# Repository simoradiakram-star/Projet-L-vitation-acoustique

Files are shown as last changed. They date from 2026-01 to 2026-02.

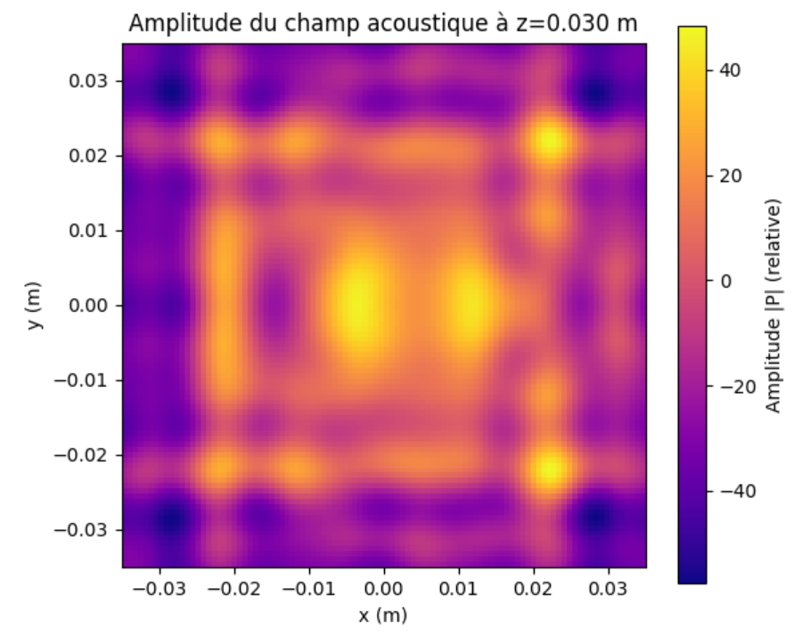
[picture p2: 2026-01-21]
Projet G1-G2/Lévitateur à une plaque/Physique théorique/Photos/vortex 1 plaque.png

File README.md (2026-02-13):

# Système de Lévitation Acoustique

**Projet (G1 / G2) — Centrale Lille**

Développement d'un dispositif expérimental de manipulation sans contact par pinces acoustiques.

Photo_lévitation_1bille_bis

---

### À propos

Ce projet vise à concevoir et réaliser un système de lévitation acoustique à **faible coût**. L'objectif principal est de permettre la manipulation sans contact d'objets millimétriques (tels que des billes de polystyrène ou de petits insectes) dans l'air.

Ce travail s'inscrit dans la continuité des recherches du groupe **AIMAN-FILMS (IEMN)**, qui développe des technologies de pinces acoustiques pour des applications biomédicales (déplacement de cellules en milieu stérile). Notre prototype adapte ces concepts pour une application macroscopique dans l'air.

---

### 1. Objectifs

* **Conception :** Réaliser un prototype fonctionnel intégrant l'électronique et la structure mécanique.
* **Manipulation :** Réussir la lévitation stable d'objets millimétriques.
* **Démonstration :** Prouver la faisabilité d'applications potentielles (ex: manipulation d'échantillons fragiles).

### 2. Technologies et Compétences

Ce projet mobilise des compétences pluridisciplinaires :

* **Hardware / Électronique :** Soudure de cartes électroniques, pilotage de transducteurs.
* **Système embarqué :** Programmation sur Arduino.
* **Mécanique :** Modélisation et Impression 3D de la structure (support des transducteurs).
* **Physique :** Principes des ondes stationnaires et de la pression de radiation acoustique.

### 3. Partenaires et Encadrement

Ce projet est réalisé en partenariat avec le groupe **AIMAN-FILMS** de l'**IEMN** (Institut d'Électronique, de Microélectronique et de Nanotechnologie).

### 4. Contacts académiques

* **Olivier Bou Matar-Lacaze** (Centrale Lille / IEMN)
* **Abdelkrim Talbi** (Centrale Lille / IEMN)

---

Voici l'architecture globale du GitHub :

```
└── Projet-Levitation-acoustique
    ├── Lévitateur à deux plaques
    │   ├── Electronique
    │   │   ├── Circuits
    │   │   └── Composants
    │   ├── Informatique
    │   │   └── Communication 2 Arduino
    │   ├── Notices
    │   ├── Physique Théorique
    │   │   ├── Calcul des phases
    │   │   └── Photos
    │   └── Résultats
    │
    ├── Lévitateur à une plaque
    │   ├── Electronique
    │   │   ├── Circuits
    │   │   └── Composants
    │   ├── Informatique
    │   │   ├── Code Arduino Mega
    │   │   │   ├── DriverMega
    │   │   │   └── NewDriverMega
    │   │   └── Codes Arduino Mega
    │   │       └── DriverMega
    │   ├── Notices
    │   ├── Physique théorique
    │   │   ├── Calcul des phases
    │   │   └── Photos
    │   └── Résultats
    │
    └── TinyLev
        └── Résultats
```

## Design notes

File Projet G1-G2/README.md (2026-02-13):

# 📁 Nos Prototypes

Ce répertoire contient 3 dossiers permettant d'identifier clairement les 3 prototypes réalisés durant notre projet, regroupés ici :

3 protos

## 1. TinyLev (Prototype de Validation)

Le **TinyLev** est un lévitateur à ondes stationnaires.

* **Objectif** : Valider les principes fondamentaux de la lévitation acoustique et tester la chaîne d'amplification.
* **Caractéristique** : Utilise deux supports imprimés en 3D suivant une courbe prédéfinie pour focaliser les ultrasons au centre.

TinyLevenfonctionnement (1)

## 2. Lévitateur à Simple Plaque

Ce prototype marque le passage au contrôle dynamique via une matrice unique de **8x8 transducteurs**.

* **Capacités** : Permet de tester les algorithmes de calcul de phase (**Optimizer** et **Vortex**).
* **Limites** : Bien qu'il valide la création de pièges acoustiques, la force de lévitation reste limitée par l'absence d'une source d'opposition, rendant le piégeage d'objets lourds complexe.



## 3. Lévitateur à Double Plaques

Version la plus aboutie du projet, elle intègre deux matrices de transducteurs placées face à face.

* **Fonctionnement** : Génère des ondes stationnaires contrôlées par la synchronisation des deux plaques.
* **Avantages** :
* Augmentation considérable de la **force de piégeage**.
* **Stabilité supérieure** permettant la manipulation de liquides ou de plusieurs particules simultanément.

Photo_lévitation_1bille_bis

---

*Pour comprendre le déroulement de notre projet plus en détail et avoir une vue d'ensemble, vous pouvez vous référer à la documentation technique située à la racine de ce dossier.*

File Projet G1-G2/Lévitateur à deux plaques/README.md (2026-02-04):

# Prototype 3 : Lévitateur à Double Plaque

Ce prototype représente l'aboutissement du projet de lévitation acoustique. En utilisant deux matrices de 64 transducteurs (8x8) placées en vis-à-vis, il permet la création d'**ondes stationnaires**, offrant une force de piégeage et une stabilité nettement supérieures au système monoplaque.

## Améliorations par rapport au Prototype 2

* **Force de lévitation accrue :** L'interaction entre les deux plaques crée des nœuds de pression beaucoup plus profonds, permettant de soulever des objets plus denses ou des liquides ;
* **Stabilité renforcée :** Le confinement acoustique est total, rendant le piège moins sensible aux courants d'air environnants ;
* **Manipulation Multi-particules :** Capacité de gérer plusieurs points de lévitation simultanément sur l'axe vertical grâce aux ondes stationnaires.

## Organisation des dossiers

### 📁 Electronique
Ce dossier détaille l'adaptation matérielle pour deux plaques :
* **Schémas** 
* **Câblage** 

### 📁 Informatique
Ce dossier contient les outils pour la gestion synchronisée :
* **Codes Arduino** 
* **Génération de phases** 

### 📁 Physique théorique
* **Calcul des phases** 
* **Comparaisons**

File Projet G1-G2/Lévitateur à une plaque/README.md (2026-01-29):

# Prototype 2 : Lévitateur à Simple Plaque (Monoplaque)

Ce prototype constitue la deuxième phase du projet. Il marque le passage d'une géométrie fixe à un système dynamique piloté par logiciel, utilisant une matrice plane de **8x8 transducteurs**.

## Raison d'être

L'objectif de ce prototype était de s'affranchir des contraintes physiques du TinyLev pour explorer la manipulation logicielle. Il a servi de banc d'essai pour :

* L'implémentation de la **modulation de phase** individuelle pour chaque transducteur ;
* La création de pièges acoustiques (points de pression) par calcul algorithmique ;
* La mise en place d'une architecture électronique capable de gérer 64 transducteurs.

## Fonctionnalités

* **Contrôle Dynamique** : Capacité à modifier la position du piège acoustique sans déplacer physiquement les transducteurs ;
* **Algorithmes Avancés** : Test et validation des méthodes **Optimizer** et **Vortex** ;
* **Interface Arduino/Python** : Liaison entre les scripts de calcul de phase (Python) et l'exécution matérielle (Arduino Mega).

## Limites

* **Force de lévitation** : En l'absence d'une plaque opposée pour créer des ondes stationnaires parfaites, la force de piégeage reste relativement faible (pression de radiation seule).
* **Stabilité** : Les objets sont sensibles à toute intervention autour de la plaque, notamment par manque de force de lévitation.

## Évolution : Vers le Prototype 3 (Double Plaque)

Pour pallier le manque de puissance et de stabilité, l'étape suivante consiste à ajouter une seconde plaque identique en vis-à-vis. Cette configuration permettra de créer des **ondes stationnaires** beaucoup plus puissantes, autorisant la lévitation de liquides et une manipulation multi-particules.

---

## 📂 Organisation des dossiers

### 📁 Electronique

Ce dossier contient les documents nécessaires à l'assemblage physique :

* **Schémas** : Diagrammes de câblage de la matrice et des drivers.
* **Montage** : Instructions pour l'interfaçage entre l'Arduino Mega et le shield de puissance.

### 📁 Informatique

Ce dossier regroupe les programmes de pilotage :

* **Génération de phases** : Scripts Python pour transformer des coordonnées (x, y, z) en signaux.
* **Code Arduino** : Firmware optimisé pour l'envoi rapide des données aux transducteurs.

### 📁 Physique théorique

* **Modèles** : Explications sur le potentiel de Gorkov et la pression de radiation.
* **Calcul des phases** : Détails mathématiques sur les fonctions de coût et les méthodes d'optimisation.

---

*Note : Pour une vue d'ensemble du projet, référez-vous à la documentation technique à la racine du dépôt.*

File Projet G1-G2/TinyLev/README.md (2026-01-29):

# Prototype 1 : TinyLev

Le **TinyLev** constitue la première étape concrète du projet. Il s'agit d'un lévitateur acoustique à ondes stationnaires dont la géométrie est fixe, permettant de valider les concepts physiques fondamentaux avant de passer à des systèmes dynamiques.

## 🎯 Raison d'être

L'objectif principal de ce prototype était de :

* Confirmer la faisabilité de la lévitation d'objets millimétriques (billes de polystyrène) ;
* Se familiariser avec la manipulation des transducteurs ultrasonores à 40 kHz.

## ✨ Fonctionnalités

* **Focalisation géométrique** : La courbure de la structure imprimée en 3D assure la convergence des faisceaux ultrasonores vers un point focal central ;
* **Ondes stationnaires** : Création de nœuds de pression stables par interférence d'ondes permettant de piéger des particules à des positions fixes ;
* **Simplicité matérielle** : Pilotage via un Arduino Nano et une alimentation directe, sans besoin de calcul de phase complexe en temps réel.

## ⚠️ Limites

* **Position fixe** : Les pièges acoustiques sont statiques : il est impossible de déplacer la particule une fois lévitée ;
* **Absence de contrôle logiciel** : Le déphasage est induit par la position physique des transducteurs et non par le code.

## ⏭️ Évolution : Vers le Prototype 2 (Monoplaque)

Le succès du TinyLev a démontré que notre électronique de puissance était fiable. Cependant, pour répondre aux objectifs de manipulation dynamique, nous avons dû abandonner la géométrie fixe au profit d'une **matrice plane (8x8)** dont nous contrôlons chacun des transducteurs individuellement.

Le passage au prototype suivant permet d'introduire le **contrôle logiciel des phases**, offrant la flexibilité nécessaire pour déplacer les pièges acoustiques et manipuler les particules dans l'espace.

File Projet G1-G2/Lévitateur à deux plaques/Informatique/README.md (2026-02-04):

# Pilotage Informatique - Prototype Double Plaque

Ce dossier contient les outils logiciels pour le contrôle du lévitateur à deux plaques (128 transducteurs). L'ajout d'une seconde plaque permet de générer des **ondes stationnaires**, offrant une stabilité et une force de lévitation supérieures au prototype précédent.

## Contenu

* **`Codes arduino mega/`** : Firmware optimisé pour l'Arduino Mega. Il gère l'envoi rapide des signaux aux deux matrices de 64 transducteurs via un mapping de ports spécifique ;
* **`Passage_Phases_python_pin.ipynb`** : Notebook de conversion. Il transforme les phases théoriques (calculées via les méthodes Optimizer ou Vortex) en séquences de bits (octets) prêtes à être injectées dans le code Arduino.

## Utilisation Rapide

1. **Calcul :** Définissez vos phases pour les 128 transducteurs dans le Notebook Python (attention à bien différencier la carte maître et esclave) ;
2. **Conversion :** Générez le "bit buffer" (le mapping prend en compte la disposition physique des deux plaques) ;
3. **Flash :** Copiez les octets générés dans la variable `patterns` du code Arduino ;
4. **Synchro :** Assurez-vous que le **pin 2** est relié au **pin 3** de l'Arduino pour la synchronisation du signal 40 kHz.

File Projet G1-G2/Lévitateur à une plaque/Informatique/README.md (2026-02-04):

# Pilotage Informatique - Lévitateur à une plaque

Ce dossier contient l'ensemble des ressources logicielles nécessaires au fonctionnement du prototype de lévitation acoustique à une plaque. 

## Structure du dossier

* **`Codes arduino mega/`** : Contient les scripts `.ino` pour l'Arduino Mega ainsi que les documentations d'explication de ces codes ;
* **`Passage_Phases_python_pin.ipynb`** : Notebook Python permettant de convertir les phases théoriques calculées en données binaires (octets) compréhensibles par l'Arduino.

---

## 🛠️ Instructions d'utilisation

### 1. Calcul des phases et conversion

Avant de téléverser le code sur l'Arduino, vous devez définir la position du piège acoustique :

1. Utilisez les scripts de calcul (Optimizer ou Vortex dans la partie physique théorique de la palque seule) pour obtenir les **phases réelles** (en radians) pour les 64 transducteurs ;
   
2. Ouvrez le notebook **`Passage_Phases_python_pin.ipynb`** ;
   
3. Renseignez vos phases réelles dans le tableau `Phi_64` ;

4. Exécutez le script pour générer le **bit buffer** (liste d'octets) ;
   
5. Copiez ces octets pour l'étape suivante.

### 2. Configuration de l'Arduino Mega

Le code de pilotage est une version optimisée du `DriverMega` original, nommée `NewDriverMega`.

1. Ouvrez le sketch dans le dossier `Codes arduino mega`.
2. Remplacez les octets de la variable `patterns` (ligne 24 environ) par ceux générés par le notebook.

3. **Note sur les motifs (patterns)** : Le code est configuré pour 2 motifs.
    * Pour un piège statique : copiez deux fois le même set de phases.
    * Pour un déplacement : renseignez deux sets de phases proches l'un de l'autre.

4. Sélectionnez la carte **Arduino Mega** dans l'IDE et téléversez le programme.

---

## ⚠️ Précautions

* **Alimentation** : Ne jamais dépasser **29V** sur la carte d'amplification.

* **Connectique** : Vérifiez la continuité des câbles en nappe, car des fils trop fins peuvent causer des pertes de signal.

* **Synchronisation** : Si le signal n'est pas stable à l'oscilloscope, ajustez ou supprimez le nombre de `nop` dans la fonction `WAIT()`.

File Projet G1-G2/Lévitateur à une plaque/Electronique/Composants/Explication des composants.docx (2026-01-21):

Explication des composants

TC 44 27 :

Le TC4427 est un driver de MOSFET conçu pour piloter des transistors MOSFET à grille à haute capacité. Il est couramment utilisé pour amplifier des signaux de commande provenant de microcontrôleurs ou d'autres circuits logiques afin de piloter des charges plus importantes.

### Fonctionnement du TC4427

- Double driver : Il contient deux drivers indépendants capables de fournir un courant de sortie élevé (jusqu'à 1,5 A en crête).
- Commande de MOSFET : Il convertit un signal logique de faible puissance en un signal de puissance plus élevé, permettant d’activer efficacement des MOSFETs.
- Sortie push-pull : Chaque canal possède une sortie de type push-pull (complètement active en montée et en descente), ce qui réduit le temps de commutation et limite les pertes de puissance.

### Caractéristiques principales

- Tension d’alimentation (Vdd) : 4,5V à 18V
- Courant de sortie : 1,5 A (max)
- Temps de commutation rapide :
  - Temps de montée : ~25 ns
  - Temps de descente : ~25 ns
- Entrée compatible logique TTL et CMOS
- Protection contre les inversions de tension d’alimentation

### Utilisation du TC4427

Le TC4427 est utilisé dans plusieurs applications, notamment :

1. Commande de MOSFETs : Pour piloter des transistors MOSFET dans des circuits de commutation ou d’amplification de puissance.
2. Alimentation à découpage (SMPS) : Pour améliorer les performances de commutation des transistors dans des convertisseurs DC-DC.
3. Commande de moteurs : Dans les circuits de contrôle de moteurs à courant continu (DC).
4. Commande de relais et solénoïdes : Pour activer des charges inductives plus importantes.
5. Circuits RF et haute fréquence : Grâce à ses temps de commutation rapides.

### Exemple de schéma d'utilisation

Si l'on souhaite piloter un MOSFET de puissance (ex : IRF540) avec un signal logique 5V issu d'un microcontrôleur (ex : Arduino), voici un schéma de base :

markdown

CopierModifier

+12V

│

│

┌┴┐

Drain │MOSFET│

└┬┘

│

├───(Charge)

│

│

GND

Le TC4427 est connecté ainsi :

- Vdd = 12V (ou 5V si besoin)
- Entrée IN = Signal du microcontrôleur (0V/5V)
- Sortie OUT = Connectée à la grille du MOSFET
- GND = Masse commune avec le circuit

Ce montage permet au microcontrôleur de commander efficacement un MOSFET de puissance sans souffrir des limitations de courant de ses broches de sortie.

### Avantages du TC4427

✅ Peut fonctionner sous une large plage de tensions (4,5V à 18V)
✅ Capable de fournir un fort courant de sortie (jusqu'à 1,5 A)
✅ Temps de commutation rapide, idéal pour des applications haute fréquence
✅ Conception robuste avec protection contre les inversions de tension

En résumé, le TC4427 est un driver MOSFET polyvalent qui améliore la commutation rapide et efficace des transistors MOSFET dans divers circuits de puissance.

### Utilité des broches :

1. IN A (Broche 1) : Entrée du premier driver (signal logique 0V ou 5V).
2. IN B (Broche 2) : Entrée du second driver (signal logique 0V ou 5V).
3. GND (Broche 3, 4, 5) : Masse du circuit (doit être connectée à la masse du système).
4. OUT B (Broche 6) : Sortie du second driver (connectée à la grille du MOSFET ou autre charge).
5. OUT A (Broche 7) : Sortie du premier driver (connectée à la grille du MOSFET ou autre charge).
6. VDD (Broche 8) : Alimentation du circuit (4.5V à 18V, selon l'application).

pour notre situation avec des transducteurs piézoélectriques :

Entrée (IN A/B) : Signal PWM venant d’un microcontrôleur (ex: Arduino).

Sortie (OUT A/B) : Connectée directement au transducteur piézoélectrique.

VDD : Tension adaptée au transducteur (ex: 12V pour une puissance plus élevée).

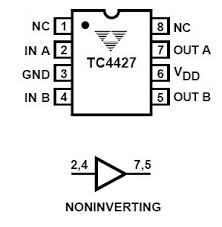
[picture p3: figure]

Les broches NC (Not Connected) sur le TC4427 (broches 1 et 8 dans ton schéma) ne sont pas connectées en interne au circuit du composant.

### Pourquoi y a-t-il des broches NC ?

1. Stabilité mécanique : Elles aident à maintenir la symétrie et la robustesse du boîtier.
2. Compatibilité avec d'autres versions : Certains boîtiers de circuits intégrés ont des broches NC pour faciliter le remplacement par des composants similaires.
3. Future évolution : Ces broches pourraient être utilisées dans des versions futures du circuit intégré.

En résumé, ces broches n'ont pas d'effet sur le fonctionnement du TC4427 et peuvent être laissées non connectées dans un circuit.

Le TC4427 contient deux drivers indépendants, ce qui permet de piloter deux MOSFETs ou charges différentes avec un seul composant. Les sorties sont push-pull, ce qui signifie qu'elles peuvent à la fois fournir du courant (source) et en absorber (sink), facilitant la commutation rapide des transistors.

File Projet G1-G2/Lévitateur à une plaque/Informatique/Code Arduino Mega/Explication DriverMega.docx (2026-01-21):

Documentation technique

Programme DriverMega.ino

Voici le code étudié :

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
#include <avr/sleep.h>

#include <avr/power.h>

#define N_PATTERNS 32

#define N_PORTS 10

#define N_DIVS 10

//ports A C L B K F H D G J

#define COMMAND_SWITCH 0b00000000

#define COMMAND_DURATION 0b00110000

#define MASK_DURATION 0b00111111

#define COMMAND_COMMITDURATIONS 0b00010000

#define WAIT(a) __asm__ __volatile__ ("nop")

#define OUTPUT_WAVE(pointer, d) PORTA = pointer[d*N_PORTS + 0]; PORTC = pointer[d*N_PORTS + 1]; PORTL = pointer[d*N_PORTS + 2]; PORTB = pointer[d*N_PORTS + 3]; PORTK = pointer[d*N_PORTS + 4]; PORTF = pointer[d*N_PORTS + 5]; PORTH = pointer[d*N_PORTS + 6]; PORTD = pointer[d*N_PORTS + 7]; PORTG = pointer[d*N_PORTS + 8]; PORTJ = pointer[d*N_PORTS + 9]

static byte bufferA[N_PATTERNS * N_DIVS * N_PORTS];

static byte bufferB[N_PATTERNS * N_DIVS * N_PORTS];

void setup()

{

//set as output ports A C L B K F H D G J

DDRA = DDRC = DDRL = DDRB = DDRK = DDRF = DDRH = DDRD = DDRG = DDRJ = 0xFF;

//low signal on all of them

PORTA = PORTC = PORTL = PORTB = PORTK = PORTF = PORTH = PORTD = PORTG = PORTJ = 0x00;

//clear the buffers

for (int i = 0; i < (N_PATTERNS * N_DIVS * N_PORTS); ++i) {

bufferA[i] = bufferB[i] = 0;

}

//initial pattern

for (int i = 0; i < (N_PORTS*N_DIVS/2); ++i){

bufferA[i] = 0xFF;

}

//a patterns of 01s at pin 22, for debuging and adjusting times

for(int i = 0; i < N_DIVS; ++i){

if (i % 2 == 0){

bufferA[i * N_PORTS] |= 0b00001000; // HIGH

bufferA[(N_PORTS * N_DIVS / 2) + i * N_PORTS] |= 0b00001000; // HIGH in lower half

} else{

bufferA[i * N_PORTS] &= 0b11110111; // LOW

bufferA[(N_PORTS * N_DIVS / 2) + i * N_PORTS] &= 0b11110111; // LOW in lower half

}

}

// generate a sync signal of 40khz in pin 2

pinMode (2, OUTPUT);

noInterrupts(); // disable all interrupts

TCCR3A = bit (WGM10) | bit (WGM11) | bit (COM1B1); // fast PWM, clear OC1B on compare

TCCR3B = bit (WGM12) | bit (WGM13) | bit (CS10); // fast PWM, no prescaler

OCR3A = (F_CPU / 40000L) - 5; //should only be -1 but fine tunning with the scope determined that -5 gave 40kHz almost exactly

OCR3B = (F_CPU / 40000L) / 2;

interrupts(); // enable all interrupts

//sync in signal at pin 3

pinMode(3, INPUT_PULLUP); //please connect pin3 to pin 2

// disable everything that we do not need

ADCSRA = 0; // ADC

power_adc_disable ();

power_spi_disable();

power_twi_disable();

power_timer0_disable();

power_usart1_disable();

power_usart2_disable();

power_usart3_disable();

//power_usart0_disable();

Serial.begin(115200);

byte bReceived = 0; //octet reçu via Serial

bool byteReady = false; //drapeau : un octet est disponible ?

bool isSwitch = false; //drapeau : commande SWITCH reçue ?

bool isPatternForMe = false; //drapeau : cet octet fait partie du pattern à charger ?

bool isDuration = false; //drapeau : cet octet contient un fragment de durée ?

bool isCommitDurations = false; //drapeau : commande de validation des durées reçue ?

byte nextMsg = 0; //valeur à renvoyer par défaut si commande inconnue

int writtingIndex = 0; //index pour l’écriture progressive d’un pattern

bool emittingA = true; //indique quel buffer (A ou B) est actuellement émis

//Pointeurs vers le début (H) et le milieu (L) du buffer A

byte* emittingPointerH = & bufferA[0];

byte* emittingPointerL = & bufferA[N_PORTS * N_DIVS / 2];

//Sauvegarde des pointeurs “à zéro” pour pouvoir réinitialiser après un switch

byte* emittingPointerZeroH = & bufferA[0];

byte* emittingPointerZeroL = & bufferA[N_PORTS * N_DIVS / 2];

//Pointeurs pour écrire dans le buffer de réception (l’autre buffer)

byte* readingPointerH = & bufferB[0];

byte* readingPointerL = & bufferB[N_PORTS * N_DIVS / 2];

byte durations[N_PATTERNS];

byte durationsBuffer[N_PATTERNS];

// On met tout à zéro

for(int i = 0; i < N_PATTERNS; ++i){

durations[i] = durationsBuffer[i] = 0;

}

// On force la durée du pattern 0 à 1 division temporelle par défaut

durations[0] = durationsBuffer[0] = 1;

byte currentPattern = 0; //motif courant dans la séquence

byte currentPeriods = 0;//compte les divisions émises dans ce motif

byte durationsPointer = 0;//index bit-à-bit lors de la réception des durées

byte currentDuration = 0;//durée lue pour le motif en cours

bool patternComplete = false;//drapeau : motif complètement émis ?

bool lastPattern = false;//drapeau : on est sur le dernier motif (31) ?

byte nextPattern = 0; //motif suivant (courant+1)

byte nextDuration = 0;//durée du motif suivant

bool returnToFirstPattern = false; //drapeau : la séquence doit revenir au motif 0 ?

LOOP:

// Attendre front descendant

while (!(PINE & 0b00100000)); // puis attendre que ça redescende (0)

OUTPUT_WAVE(emittingPointerH, 0); //émission des 8 bits de chaque port à la division 0

byteReady = Serial._dataAvailable(); //on vérifie si un octet est déjà arrivé dans le buffer matériel du Serial

OUTPUT_WAVE(emittingPointerH, 1); //émission de la division 1

bReceived = Serial._peekData(); //on lit l’octet en tête si présent, mais on ne le retire pas du buffer.

OUTPUT_WAVE(emittingPointerH, 2); //émission de la division 2

isSwitch = bReceived == COMMAND_SWITCH; //si l’octet cumulé vaut exactement 0x00, on prépare le flag “switch buffer”.

isCommitDurations = bReceived == COMMAND_COMMITDURATIONS; //même principe pour la validation des durées

OUTPUT_WAVE(emittingPointerH, 3); //émission de la division 3

isPatternForMe = (bReceived & 0b00001111) == 1; //on regarde les 4 LSB pour voir si ce byte contient un fragment du pattern

++currentPeriods; //on incrémente le compteur de périodes déjà émises pour le motif courant.

OUTPUT_WAVE(emittingPointerH, 4); //émission de la division 4

nextMsg = bReceived - 1; //pré-calcule la réponse générique (ack ou message d’erreur minimaliste.

OUTPUT_WAVE(emittingPointerL, 0); //émission de la division 0

isDuration = (bReceived & MASK_DURATION) == COMMAND_DURATION; //on masque les 6 LSB et compare à 0x30 : détecte un byte “durée”.

nextPattern = currentPattern + 1; //on anticipe l’index du motif suivant

OUTPUT_WAVE(emittingPointerL, 1); //émission de la division 1

nextDuration = durations[nextPattern]; //lecture de la durée stockée pour le motif suivant

OUTPUT_WAVE(emittingPointerL, 2); //émission de la division 2

patternComplete = (currentPeriods == durations[currentPattern]);//vrai si on a déjà émis autant de divisions que la durée allouée au motif en cours

OUTPUT_WAVE(emittingPointerL, 3); //émission de la division 3

lastPattern = (currentPattern+1 == N_PATTERNS); //vrai si on était sur le dernier motif (31)

returnToFirstPattern = nextDuration == 0; //vrai si le motif suivant est configuré pour durer 0 divisions.

OUTPUT_WAVE(emittingPointerL, 4); //émission de la division 4

if (patternComplete){

currentPeriods = 0;

++currentPattern;

if (lastPattern || returnToFirstPattern){

currentPattern = 0;

emittingPointerH = emittingPointerZeroH;

emittingPointerL = emittingPointerZeroL;

}else{

emittingPointerH += (N_DIVS * N_PORTS);

emittingPointerL += (N_DIVS * N_PORTS);

}

}

if (byteReady) {

if (isSwitch) {

// --- SWITCH BUFFER ---

Serial.write(COMMAND_SWITCH);

emittingA = !emittingA;

// On swap A↔B pour émission vs. réception

if (emittingA) {

emittingPointerH = &bufferA[0];

emittingPointerL = &bufferA[N_PORTS*N_DIVS/2];

readingPointerH = &bufferB[0];

readingPointerL = &bufferB[N_PORTS*N_DIVS/2];

} else {

emittingPointerH = &bufferB[0];

emittingPointerL = &bufferB[N_PORTS*N_DIVS/2];

readingPointerH = &bufferA[0];

readingPointerL = &bufferA[N_PORTS*N_DIVS/2];

}

emittingPointerZeroH = emittingPointerH;

emittingPointerZeroL = emittingPointerL;

writtingIndex = 0;

durationsPointer = 0;

} else if (isPatternForMe) {

// --- RÉCEPTION D’UN OCTET DE PATTERN ---

// On compose 4 bits hauts et 4 bits bas dans readingPointerH[]

if (writtingIndex % 2 == 0)

readingPointerH[writtingIndex/2] = bReceived & 0xF0;

} else {

readingPointerH[writtingIndex/2] |= (bReceived >> 4);

}

++writtingIndex;

} else if (isDuration) {

// --- RÉCEPTION D’UN OCTET DE DURÉE —

Serial.write( bReceived );

if (durationsPointer % 4 == 0) {

durationsBuffer[durationsPointer / 4] = bReceived & 0b11000000;

} else {

durationsBuffer[durationsPointer / 4] |= (bReceived & 0b11000000) >> (durationsPointer % 4 * 2);

}

++durationsPointer;

} else if (isCommitDurations) {

// --- COMMIT DES DURÉES —

Serial.write(bReceived);

for (int i = 0; i < N_PATTERNS; ++i){

durations[i] = durationsBuffer[i];

}

durationsPointer = 0;

} else {

// --- COMMANDE INCONNUE —

Serial.write(nextMsg);

}

// On consomme enfin l’octet

Serial._discardByte();

}

void loop() {}

## 1. Commentaires d’en-tête et instructions de compilation

Les premiers commentaires (lignes 1–11) indiquent :

- Qu’il faut ajouter trois fonctions inline dans HardwareSerial.h pour accéder aux octets reçus (_dataAvailable(), _peekData(), _discardByte()).
- Que, pour la version Arduino IDE > 1.6, il faut compiler avec l’option -O3 (optimisation vitesse).
- De commenter la ligne power_usart3_disable(); si elle génère une erreur.

Ces ajustements sont purement pour contourner des limitations de la bibliothèque HardwareSerial et d’optimiser le code.

## 2. Inclusion de bibliothèques et définitions de constantes

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
#include <avr/sleep.h>

#include <avr/power.h>

#define N_PATTERNS 32

#define N_PORTS 10

#define N_DIVS 10

//ports A C L B K F H D G J

#define COMMAND_SWITCH 0b00000000

#define COMMAND_DURATION 0b00110000

#define MASK_DURATION 0b00111111

#define COMMAND_COMMITDURATIONS 0b00010000

#define WAIT(a) __asm__ __volatile__ ("nop")

#define OUTPUT_WAVE(pointer, d) PORTA = pointer[d*N_PORTS + 0]; PORTC = pointer[d*N_PORTS + 1]; PORTL = pointer[d*N_PORTS + 2]; PORTB = pointer[d*N_PORTS + 3]; PORTK = pointer[d*N_PORTS + 4]; PORTF = pointer[d*N_PORTS + 5]; PORTH = pointer[d*N_PORTS + 6]; PORTD = pointer[d*N_PORTS + 7]; PORTG = pointer[d*N_PORTS + 8]; PORTJ = pointer[d*N_PORTS + 9]

- COMMAND_SWITCH : Indique “change de buffer” : dès qu’un octet reçu vaut exactement 0, on bascule l’émission de bufferA vers bufferB (ou inverse). Switch permet donc de passer de l’écriture dans un buffer à l’émission de l’autre, garantissant une mise à jour sans artefacts.
- COMMAND_DURATION : Motif de bits en position haute (b5 et b4 à 1) signalant le transfert de données de durée (2 bits × 4). Duration découpe donc chaque durée sur 2 bits, stockés à raison de 4 octets par pattern (2 bits × 4 = 8 bits), grâce au masque.
- MASK_DURATION : Masque pour extraire les 6 bits de poids faible du byte reçu : on l’applique par bReceived & MASK_DURATION pour isoler la partie “commande + payload” sans les bits supérieurs réservés.
- COMMAND_COMMITDURATIONS : Valeur précise (b4 à 1, b5 à 0) qui, une fois reconnue, commande la validation de toutes les durées accumulées dans durationsBuffer[] vers durations[]. CommitDurations confirme donc à l’Arduino qu’il peut désormais utiliser les nouvelles durées pour cadencer la lecture des patterns.

Utilisation dans le programme :

1. Détection d’une commande “switch”

131 | isSwitch = (bReceived == COMMAND_SWITCH);

Si l’octet reçu vaut 0b00000000, on sait que l’hôte veut que l’Arduino bascule le buffer actif d’émission.

2. Détection d’un octet de “durée”

134 | isDuration = ((bReceived & MASK_DURATION) == COMMAND_DURATION);

- On applique bReceived & 0b00111111 pour garder les 6 bits de poids faible.
- Si le résultat vaut 0b00110000, l’octet transporte un fragment de durée à stocker dans durationsBuffer.
3. Détection de la commande de “commit” des durées

131 | isCommitDurations = (bReceived == COMMAND_COMMITDURATIONS);

Quand l’octet reçu vaut 0b00010000, on sait que l’envoi de durées est terminé ; on copie alors durationsBuffer dans durations.

- N_PATTERNS (32) : nombre de motifs/patterns stockés.
- N_PORTS (10) et N_DIVS (10) déterminent la taille des buffers: chaque pattern comporte 10 ports et 10 divisions temporelles.

28 | #define WAIT(a) __asm__ __volatile__ ("nop")

- nop (No OPeration) est une instruction assembleur qui ne fait rien, elle coûte un cycle d’horloge.
- Rôle : insérer un tout petit délai (exactement 1 cycle CPU) à l’endroit où la macro est appelée.
- Paramètre a : n’est pas utilisé dans la macro ; c’est souvent un artifice pour conserver la même syntaxe (WAIT(5) par exemple) si on veut lier la macro à un argument, ou pour documenter l’intention.
- Usage typique : ajuster le placement des instructions en mémoire ou entre deux accès à un port pour garantir un échantillonnage stable ou éviter des métastabilités.

29 29 29 29 29 29 | #define OUTPUT_WAVE(pointer, d) PORTA = pointer[d*N_PORTS + 0]; PORTC = pointer[d*N_PORTS + 1]; PORTL = pointer[d*N_PORTS + 2]; PORTB = pointer[d*N_PORTS + 3]; PORTK = pointer[d*N_PORTS + 4]; PORTF = pointer[d*N_PORTS + 5]; PORTH = pointer[d*N_PORTS + 6]; PORTD = pointer[d*N_PORTS + 7]; PORTG = pointer[d*N_PORTS + 8]; PORTJ = pointer[d*N_PORTS + 9]

Cette macro écrit en un seul appel sur les 10 registres de port (A, C, L, B, K, F, H, D, G, J) la valeur contenue dans un buffer.

- pointer : pointeur sur un tableau byte qui contient, pour chaque “division temporelle” et chaque port, la valeur à appliquer (0 ou 1 dans chaque bit du port).
- d : indice de la “division temporelle” courante (allant de 0 à N_DIVS–1).
- d*N_PORTS + i : calcule l’offset dans le buffer pour le i-ème port (i=0…9).
- Chaque instruction PORTx = …; écrit 8 bits d’un coup sur le port .

## 3. Déclaration des buffers globaux

Deux buffers (A et B) permettent de stocker en double buffer des trames de sortie : pendant qu’on émet l’un, on remplit l’autre via la liaison série.

31 32 | static byte bufferA[N_PATTERNS * N_DIVS * N_PORTS]; static byte bufferB[N_PATTERNS * N_DIVS * N_PORTS];

## 4. Configuration de la fonction setup()

### 4.1. Configuration des broches

On configure d’abord les registres de direction :

34 35 36 37 37 | void setup() { //set as output ports A C L B K F H D G J DDRA = DDRC = DDRL = DDRB = DDRK = DDRF = DDRH = DDRD = DDRG = DDRJ = 0xFF;

- Sur le microcontrôleur ATmega2560 de l’Arduino Mega, chaque port (A, C, L, B, K, F, H, D, G, J) possède un registre DDR (Data Direction Register).
- Mettre un bit à 1 dans DDRX configure la broche correspondante du port en sortie.
- 0xFF en hexadécimal, soit binaire 11111111, fixe tous les 8 bits à 1 : toutes les broches des ports A, C, L, B, K, F, H, D, G et J deviennent des sorties.

On met ensuite à 0 tous les ports :

38 39 39 | //low signal on all of them PORTA = PORTC = PORTL = PORTB = PORTK = PORTF = PORTH = PORTD = PORTG = PORTJ = 0x00;

Le registre PORTX contrôle le niveau logique appliqué aux broches configurées en sortie. En écrivant 0x00 (binaire 00000000), on place tout le port à LOW, c’est-à-dire 0 V sur chaque broche. Ceci garantit qu’au démarrage, aucun signal indésirable n’est émis.

Enfin, on initialise les buffers de motif :

41 42 43 44 | //clear the buffers for (int i = 0; i < (N_PATTERNS * N_DIVS * N_PORTS); ++i) { bufferA[i] = bufferB[i] = 0; }

- Les deux tableaux bufferA et bufferB contiennent les valeurs à envoyer, à chaque pas de temps, sur les 10 ports.
- Leur taille totale est N_PATTERNS * N_DIVS * N_PORTS octets.
  - N_PATTERNS : nombre de motifs différents stockables (32).
  - N_DIVS : nombre de “divisions temporelles” par motif (10).
  - N_PORTS : nombre de ports émis en parallèle (10).
- Cette boucle for met tous les éléments de ces deux buffers à zéro, assurant un état connu (aucun bit à 1) avant de charger un motif ou une séquence.

### 4.2. Initialisation et “pattern” de base

On commence par remplir la moitié haute du bufferA à 0xFF :

46 47 48 49 | //initial pattern for (int i = 0; i < (N_PORTS*N_DIVS/2); ++i){ bufferA[i] = 0xFF; }

- N_PORTS * N_DIVS est le nombre d’octets par pattern.
- Divisé par 2, cela correspond à la première moitié du pattern (on émettra deux “moitiés” successives de N_DIVS divisions).
- En mettant chaque bufferA[i] = 0xFF, on fait en sorte que tous les bits (toutes les broches des 10 ports) soient à 1 (HIGH) pour cette première moitié temporelle.
- La deuxième moitié du buffer (indices ≥ N_PORTS * N_DIVS / 2) reste à 0, donc toutes sorties à LOW.

Cette organisation (division en 2 du buffer) permet de simplifier l’organisation de la mémoire et celle du double buffering ainsi que de gagner en souplesse sur l’émission des patterns.

### 4.3. Debug

On y superpose un signal de 0 et de 1 sur la broche 22 (pour debug):

52 53 54 55 56 56 57 58 59 60 61 62 | //a patterns of 01s at pin 22, for debuging and adjusting times for(int i = 0; i < N_DIVS; ++i){ if (i % 2 == 0){ bufferA[i * N_PORTS] |= 0b00001000; // HIGH bufferA[(N_PORTS * N_DIVS / 2) + i * N_PORTS] |= 0b00001000; // HIGH in lower half } else{ bufferA[i * N_PORTS] &= 0b11110111; // LOW bufferA[(N_PORTS * N_DIVS / 2) + i * N_PORTS] &= 0b11110111; // LOW in lower half } }

- Index de l’octet correspondant à la broche 22 (PA3) pour la division temporelle i :
  - Première moitié → i * N_PORTS + 0 (le port A est à l’emplacement +0)
  - Seconde moitié → (N_PORTS * N_DIVS / 2) + i * N_PORTS + 0
- Masque 0b00001000 : active ou désactive le bit 3 de l’octet, c’est-à-dire PA3.
- Pour i pair on fait un OR (|= 0b00001000) → PA3 = HIGH.
- Pour i impair on fait un AND avec l’inverse (&= 0b11110111) → PA3 = LOW.

Ainsi, au cours des 10 divisions temporelles, PA3 passera alternativement à 1 puis 0 (motif “0101…”), et cela sur les deux moitiés de bufferA.

En gros cela allume la pin22 alternativement (c’est 5 mini créneaux) et cela permet de vérifier que tout fonctionne bien.

### 4.3. Génération d’un signal de synchronisation à 40 kHz (broche 2)

Cette section configure le Timer 3 de l’ATmega pour générer, matériellement, un signal carré synchronisé à 40 kHz sur la broche associée à OC3B (reliée à D2).

66 67 68 69 69 70 70 71 71 72 73 | // generate a sync signal of 40khz in pin 2 pinMode (2, OUTPUT); noInterrupts(); // disable all interrupts TCCR3A = bit (WGM10) | bit (WGM11) | bit (COM1B1); // fast PWM, clear OC1B on compare TCCR3B = bit (WGM12) | bit (WGM13) | bit (CS10); // fast PWM, no prescaler OCR3A = (F_CPU / 40000L) - 5; //should only be -1 but fine tunning with the scope determined that -5 gave 40kHz almost exactly OCR3B = (F_CPU / 40000L) / 2; interrupts(); // enable all interrupts

Elle :

- Met la broche 2 en sortie (c’est là que sortira le signal PWM).

PWM = Pulse Width Modulation → modulation de largeur d’impulsion :

1. C’est un signal numérique (0 ou 1, HIGH ou LOW) dont la fréquence est fixe, mais la durée pendant laquelle il reste à 1 varie.
2. En d’autres termes, on “allume” et “éteint” rapidement une broche pour créer un signal dont la moyenne sur le temps peut représenter une valeur analogique.
- Désactive temporairement toutes les interruptions pour éviter qu’un appel en ISR ne perturbe la configuration fine des registres du timer.
- Mode Fast PWM, TOP = OCR3A
  - Les quatre bits WGM13:WGM10 à 1 sélectionnent le mode 15 (Fast PWM, TOP variable).
  - En mode non-inverting (COM3B1=1), la sortie OC3B passe à HIGH au début de la période (compteur = 0) et se remet à LOW quand le compteur atteint OCR3B.
- CS10 = 1 → on utilise directement la fréquence CPU (F_CPU) sans division.
- CR3A fixe la valeur de comparaison qui détermine la période du PWM :

On soustrait “–5” au lieu de “–1” pour un ajustement au scope, afin d’obtenir précisément 40 kHz à cause de tolérances matérielles.

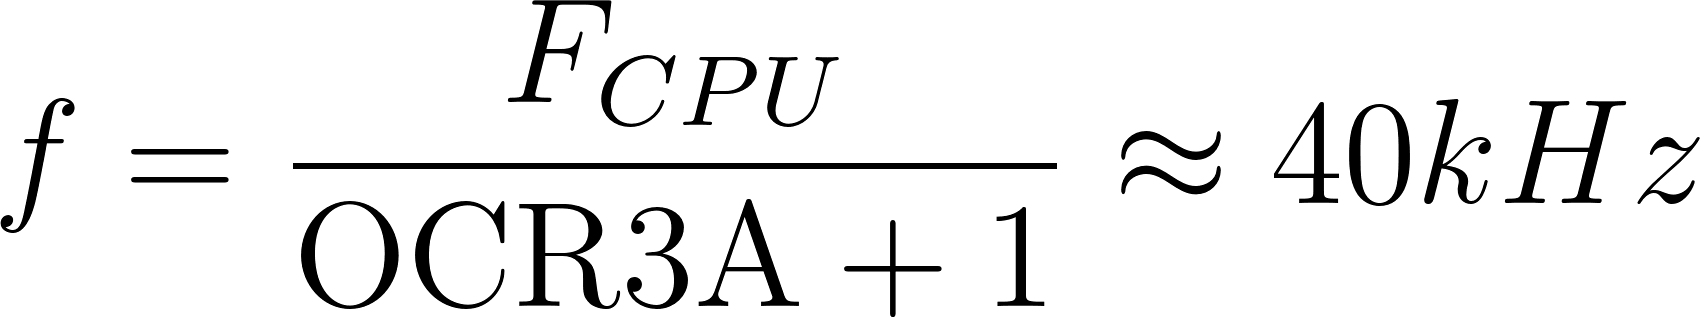
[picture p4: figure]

- OCR3B à la moitié de OCR3A → génère un rapport cyclique 50 %.
- Restaure les interruptions maintenant que le timer est configuré.

A quoi sert une horloge ?

4️⃣ Analogie

Imagine un orchestre :

- Chaque musicien joue sa note quand il voit le chef d’orchestre lever la main.
- Ici :
  - Le signal PWM 40 kHz = chef d’orchestre
  - Les transducteurs = musiciens
  - Chaque impulsion du signal indique quand mettre à jour le pattern sur les sorties.

Sans ce signal, chacun jouerait à sa propre vitesse → le motif acoustique serait détruit.

5️⃣ Résumé

- Le signal de 40 kHz est l’horloge de référence du système.
- Il garantit que tous les transducteurs changent d’état exactement au même moment.
- Sans lui, la lévitation acoustique ne serait pas stable.

### 4.4. Entrée de synchronisation (broche 3)

75 76 | //sync in signal at pin 3 pinMode(3, INPUT_PULLUP); //please connect pin3 to pin 2

On attend un front descendant sur pin 3 connecté à pin 2 pour cadencer la boucle d’émission.

### 4.5. Désactivation des périphériques non utilisés pour économiser l’énergie

79 80 81 82 83 84 85 86 87 88 | // disable everything that we do not need ADCSRA = 0; // ADC power_adc_disable (); power_spi_disable(); power_twi_disable(); power_timer0_disable(); power_usart1_disable(); power_usart2_disable(); power_usart3_disable(); //power_usart0_disable();

On garde tout de même le port USART0 activé afin de pouvoir utiliser la communication série avec l’application Java.

### 3.6. Initialisation du port série et variables de protocole

On initialise tout d’abord le port série en configurant l’USART0 à 115 200 bauds pour l’échange de commandes et de données avec l’hôte (PC ou microcontrôleur maître). :

90 | Serial.begin(115200);

Ensuite, on déclare les variables de réception :

92 93 94 95 95 96 96 97 97 98 98 99 99 | byte bReceived = 0; //octet reçu via Serial bool byteReady = false; //drapeau : un octet est disponible ? bool isSwitch = false; //drapeau : commande SWITCH reçue ? bool isPatternForMe = false; //drapeau : cet octet fait partie du pattern à charger ? bool isDuration = false; //drapeau : cet octet contient un fragment de durée ? bool isCommitDurations = false; //drapeau : commande de validation des durées reçue ? byte nextMsg = 0; //valeur à renvoyer par défaut si commande inconnue int writtingIndex = 0; //index pour l’écriture progressive d’un pattern

Ces drapeaux sont recalculés à chaque itération de la boucle principale pour parser l’octet reçu (bReceived).

Puis, il faut gérer la double bufférisation :

101 101 102 103 104 105 106 107 | bool emittingA = true; //indique quel buffer (A ou B) est actuellement émis //Pointeurs vers le début (H) et le milieu (L) du buffer A byte* emittingPointerH = & bufferA[0]; byte* emittingPointerL = & bufferA[N_PORTS * N_DIVS / 2]; //Sauvegarde des pointeurs “à zéro” pour pouvoir réinitialiser après un switch byte* emittingPointerZeroH = & bufferA[0]; byte* emittingPointerZeroL = & bufferA[N_PORTS * N_DIVS / 2]; //Pointeurs pour écrire dans le buffer de réception (l’autre buffer) byte* readingPointerH = & bufferB[0]; byte* readingPointerL = & bufferB[N_PORTS * N_DIVS / 2];

- emittingPointerH/L pointent sur la moitié active du buffer à émettre (la première moitié des divisions temporelles puis la seconde).
- readingPointerH/L pointent sur la moitié correspondante de l’autre buffer, où les nouveaux motifs seront chargés.
- Quand on reçoit la commande SWITCH, on inverse emittingA et on échange simplement ces pointeurs entre A et B.

Vient alors l’initialisation des durées de pattern :

109 110 111 112 113 114 | byte durations[N_PATTERNS]; byte durationsBuffer[N_PATTERNS]; // On met tout à zéro for(int i = 0; i < N_PATTERNS; ++i){ durations[i] = durationsBuffer[i] = 0; } // On force la durée du pattern 0 à 1 division temporelle par défaut durations[0] = durationsBuffer[0] = 1;

- durations[] stocke pour chaque motif (0 à 31) le nombre de divisions temporelles pendant lesquelles il reste actif.
- durationsBuffer[] sert à accumuler les nouvelles durées reçues avant le commit.
- On met par défaut le pattern 0 à durer 1 division, pour éviter une division par zéro lors du premier cycle.

Finalement, on met à jour les variables qui contrôlent le cycle d’émission :

116 117 118 119 120 121 122 123 124 | byte currentPattern = 0; //motif courant dans la séquence byte currentPeriods = 0;//compte les divisions émises dans ce motif byte durationsPointer = 0;//index bit-à-bit lors de la réception des durées byte currentDuration = 0;//durée lue pour le motif en cours bool patternComplete = false;//drapeau : motif complètement émis ? bool lastPattern = false;//drapeau : on est sur le dernier motif (31) ? byte nextPattern = 0; //motif suivant (courant+1) byte nextDuration = 0;//durée du motif suivant bool returnToFirstPattern = false; //drapeau : la séquence doit revenir au motif 0 ?

- currentPattern et currentPeriods gèrent la progression au sein des divisions temporelles du pattern actif.
- À chaque front de synchronisation, on incrémente currentPeriods ; quand il atteint durations[currentPattern], patternComplete passe à true et on avance currentPattern.
- Si on est arrivé au pattern final (31) ou si la durée du suivant est nulle, on revient au motif 0.

### 3.5. Boucle principale avec goto LOOP

Contrairement au style habituel void loop(), ici on utilise un label LOOP: et un goto pour réduire le code généré par l’IDE.

### 3.5.1. Synchronisation sur front descendant (cycle PWM 40 kHz)

125 126 127 | LOOP: // Attendre front descendant while (!(PINE & 0b00100000)); // puis attendre que ça redescende (0)

Comme cette broche (PE5) est raccordée au signal PWM de pin 2 via pin 3, on se positionne sur le front montant, puis le code suivant attendra la descente effective du signal avant la prochaine itération.

- PE5 correspond à la broche 3 ; ce signal est le reflet du PWM 40 kHz généré sur la broche 2.
- On synchronise ainsi chaque itération de la boucle sur une période complète du signal de référence, garantissant un timing constant.

### 3.5.2. Emission du motif et évaluation du byte série

Chaque itération, on exécute successivement cinq appels à la macro OUTPUT_WAVE(...), envoyant les octets préparés dans emittingPointerH[] pour les divisions temporelles 0→4, puis cinq pour emittingPointerL[], divisions 0→4 de la seconde moitié du pattern :

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
OUTPUT_WAVE(emittingPointerH, 0); //émission des 8 bits de chaque port à la division 0

byteReady = Serial._dataAvailable(); //on vérifie si un octet est déjà arrivé dans le buffer matériel du Serial

OUTPUT_WAVE(emittingPointerH, 1); //émission de la division 1

bReceived = Serial._peekData(); //on lit l’octet en tête si présent, mais on ne le retire pas du buffer.

OUTPUT_WAVE(emittingPointerH, 2); //émission de la division 2

isSwitch = bReceived == COMMAND_SWITCH; //si l’octet cumulé vaut exactement 0x00, on prépare le flag “switch buffer”.

isCommitDurations = bReceived == COMMAND_COMMITDURATIONS; //même principe pour la validation des durées

OUTPUT_WAVE(emittingPointerH, 3); //émission de la division 3

isPatternForMe = (bReceived & 0b00001111) == 1; //on regarde les 4 LSB pour voir si ce byte contient un fragment du pattern

++currentPeriods; //on incrémente le compteur de périodes déjà émises pour le motif courant.

OUTPUT_WAVE(emittingPointerH, 4); //émission de la division 4

nextMsg = bReceived - 1; //pré-calcule la réponse générique (ack ou message d’erreur minimaliste.

OUTPUT_WAVE(emittingPointerL, 0); //émission de la division 0

isDuration = (bReceived & MASK_DURATION) == COMMAND_DURATION; //on masque les 6 LSB et compare à 0x30 : détecte un byte “durée”.

nextPattern = currentPattern + 1; //on anticipe l’index du motif suivant

OUTPUT_WAVE(emittingPointerL, 1); //émission de la division 1

nextDuration = durations[nextPattern]; //lecture de la durée stockée pour le motif suivant

OUTPUT_WAVE(emittingPointerL, 2); //émission de la division 2

patternComplete = (currentPeriods == durations[currentPattern]);//vrai si on a déjà émis autant de divisions que la durée allouée au motif en cours

OUTPUT_WAVE(emittingPointerL, 3); //émission de la division 3

lastPattern = (currentPattern+1 == N_PATTERNS); //vrai si on était sur le dernier motif (31)

returnToFirstPattern = nextDuration == 0; //vrai si le motif suivant est configuré pour durer 0 divisions.

OUTPUT_WAVE(emittingPointerL, 4); //émission de la division 4

Pour chaque division temporelle d :

1. OUTPUT_WAVE écrit en parallèle sur les 10 ports la valeur pointer[d*N_PORTS + i].
2. Au deuxième appel (d=1), on lit si un octet est prêt :
  - byteReady = Serial._dataAvailable();
  - bReceived = Serial._peekData(); On ne consomme pas encore l’octet, juste on le lit pour décider de la suite.
3. Entre les écritures, on calcule divers drapeaux et compteurs en fonction de bReceived :
  - isSwitch, isCommitDurations
  - isPatternForMe (on regarde les 4 LSB (= bit de point faible) pour voir si ce pattern est destiné à cet esclave)
  - nextMsg = bReceived - 1 : valeur par défaut à renvoyer si commande inconnue
  - isDuration pour détecter l’octet de durée
  - nextPattern, nextDuration : préparation pour tester si on doit repasser au motif 0
  - patternComplete dès que le nombre de divisions émises atteint durations[currentPattern]
  - lastPattern si on est sur le dernier motif (31)
  - returnToFirstPattern si la durée du suivant vaut 0

Par cette alternance d’OUTPUT_WAVE et de calculs, on s’assure que l’émission reste cycle-exacte à 40 kHz, tout en “streamant” le protocole série en arrière-plan.

### 3.5.3 Avancement du motif

Après les 10 divisions temporelles, on regarde si patternComplete est vrai :

140 141 142 143 144 145 146 147 148 149 150 151 | if (patternComplete){ currentPeriods = 0; ++currentPattern; if (lastPattern || returnToFirstPattern){ currentPattern = 0; emittingPointerH = emittingPointerZeroH; emittingPointerL = emittingPointerZeroL; }else{ emittingPointerH += (N_DIVS * N_PORTS); emittingPointerL += (N_DIVS * N_PORTS); } }

- currentPeriods remis à zéro pour compter de nouvelles divisions.
- currentPattern incrémenté, ou remis à 0 si fin de séquence ou durée nulle.
- emittingPointerH/L avancent de N_DIVS*N_PORTS octets pour pointer vers la prochaine moitié de buffer à émettre.

### 3.5.4 Gestion du protocole série

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
if (byteReady) {

if (isSwitch) {

// --- SWITCH BUFFER ---

Serial.write(COMMAND_SWITCH);

emittingA = !emittingA;

// On swap A↔B pour émission vs. réception

if (emittingA) {

emittingPointerH = &bufferA[0];

emittingPointerL = &bufferA[N_PORTS*N_DIVS/2];

readingPointerH = &bufferB[0];

readingPointerL = &bufferB[N_PORTS*N_DIVS/2];

} else {

emittingPointerH = &bufferB[0];

emittingPointerL = &bufferB[N_PORTS*N_DIVS/2];

readingPointerH = &bufferA[0];

readingPointerL = &bufferA[N_PORTS*N_DIVS/2];

}

emittingPointerZeroH = emittingPointerH;

emittingPointerZeroL = emittingPointerL;

writtingIndex = 0;

durationsPointer = 0;

} else if (isPatternForMe) {

// --- RÉCEPTION D’UN OCTET DE PATTERN ---

// On compose 4 bits hauts et 4 bits bas dans readingPointerH[]

if (writtingIndex % 2 == 0)

readingPointerH[writtingIndex/2] = bReceived & 0xF0;

} else {

readingPointerH[writtingIndex/2] |= (bReceived >> 4);

}

++writtingIndex;

} else if (isDuration) {

// --- RÉCEPTION D’UN OCTET DE DURÉE —

Serial.write( bReceived );

if (durationsPointer % 4 == 0) {

durationsBuffer[durationsPointer / 4] = bReceived & 0b11000000;

} else {

durationsBuffer[durationsPointer / 4] |= (bReceived & 0b11000000) >> (durationsPointer % 4 * 2);

}

++durationsPointer;

} else if (isCommitDurations) {

// --- COMMIT DES DURÉES —

Serial.write(bReceived);

for (int i = 0; i < N_PATTERNS; ++i){

durations[i] = durationsBuffer[i];

}

durationsPointer = 0;

} else {

// --- COMMANDE INCONNUE —

Serial.write(nextMsg);

}

// On consomme enfin l’octet

Serial._discardByte();

}

- Switch : confirme au maître, échange les rôles des buffers A/B.
- PatternForMe : assemble un motif 10 bits (2×4 bits) dans readingPointerH.
- Duration : stocke progressivement 2 bits×4 octets par motif dans durationsBuffer.
- CommitDurations : valide toutes les nouvelles durées en copiant le tampon tampon.
- Inconnu : renvoie nextMsg = bReceived–1 pour signaler une erreur ou un ack générique.

## 5. Fonction loop() vide

1 2 3 | } void loop() {}

La boucle loop() reste vide puisqu’on utilise goto LOOP dès setup() pour la boucle principale.

Conclusion :

Le programme gère une double-bufferisation de motifs (bufferA, bufferB) envoyés simultanément sur 10 ports à une fréquence de division temporelle fixée (40 kHz). Les motifs et leurs durées sont reçus par le port série selon un protocole léger :

- Switch pour permuter buffer émis/réception,
- PatternForMe pour charger les octets de pattern,
- Duration pour charger les durées de chaque pattern,
- CommitDurations pour valider les durées reçues.

Le tout est synchronisé par un signal PWM 40 kHz (pin 2→pin 3) et optimisé pour la basse consommation en désactivant les périphériques inutiles.

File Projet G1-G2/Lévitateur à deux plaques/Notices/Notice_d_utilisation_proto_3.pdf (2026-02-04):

# NOTICE D’UTILISATION : LÉVITATEUR À DEUX PLAQUES

## Contrôle Synchrone Maître-Esclave (Prototype 3)

### 4 février 2026

## Sommaire

1 Étapes clés | 2
2 Prise en main des codes Arduino | 2
3 Prise en main pratique | 4
A Annexes techniques | 7

## 1 Étapes clés

1. Prise en main des codes Arduino
2. Prise en main pratique

## 2 Prise en main des codes Arduino

Ce troisième prototype nécessitant l’utilisation de 2 plaques de lévitation contrôlables de façon indépendantes, il est alors nécessaire d’utiliser 2 cartes Arduino et donc d’être capable de les faire fonctionner de façon synchrone. Pour ce faire, nous avons mis en place un système maître-esclave. Les codes utilisés sont présentés en Annexe.

Le fonctionnement de ce système est assez basique : les phases à émettre sur chacune des deux plaques sont stockées "en dur" (dans le code) dans chacune des deux cartes Arduino, ce qui permet de ne pas avoir à gérer le transfert des octets de l’Arduino maître vers l’Arduino esclave.

La communication entre les 2 deux cartes Arduino se résume donc à leur synchronisation sur le signal créneau du pin 2 de la carte maître permettant de cadencer l’émission des signaux pour les 64 transducteurs. Le fonctionnement schématisé de la communication entre les 2 programmes est repris par la figure suivante.

Ouverture de la
communication Serial à
115200 bauds

Serial
available
?

Non

Oui

Envoi d’un caractère
quelconque via le Serial
Monitor

Mise sous tension des
2 Arduino

Caractère
reçu par
l’esclave ?

Non

Oui
Envoi de l’octet 0x55 par le maître

Octet reçu
par
l’eclave ?

Non

Tick reçu
sur le pin 3
?

Emission de la partie H du buffer

Emission de la partie L du buffer

LOOP

STOP

Pause de 10 cycles de
processeur

## Initialisation Synchronisation

## Emission

Figure 1 – Schéma explicatif de la communication entre les 2 cartes Arduino

### 2.1 Initialisation

Cette première partie des codes est tout à fait similaire à celle du code NewDriverMega disponible sur GitHub (https://github.com/simoradiakram-star/Projet-Levitation-acoustique) et est commune aux deux cartes Arduino.

Dans cette phase d’initialisation, les deux cartes Arduino configurent les constantes, les différentes variables qui seront utilisées ainsi que l’ensemble des ports parallèles (A, C, L, B, K, F, H, D, G et J) en sortie et les placent à l’état bas afin de garantir un état initial stable pour les transducteurs. Elles effacent ensuite le buffer contenant les données d’émission pour éviter toute valeur résiduelle.

La configuration de l’interruption INT5 (sur la broche 3) est mise en place pour détecter chaque front descendant du signal de synchronisation envoyé par la carte maître ; cette interruption alimente un compteur sync_cnt utilisé comme horloge externe.

Enfin, les modules inutiles du microcontrôleur (ADC, SPI, TWI, certains timers et ports série) sont désactivés afin de réduire la charge et d’assurer un fonctionnement précis et déterministe, ce qui est essentiel pour la génération synchrone des signaux.

Il est à noter que le code maître possède une étape qui est absente dans le code esclave : l’émission du signal de synchronisation à 80 kHz. En effet, la carte esclave n’a pas besoin d’émettre ce signal puisque sa broche 3 est directement connectée à la broche 2 de l’Arduino maître, ce qui lui permet de se synchroniser sur le signal du maître.

Remarque : il est à noter que nous avons fait le choix d’utiliser un signal de synchronisation à 80 kHz et non plus à 40 kHz comme précédemment. Cela résulte uniquement de contraintes informatiques liées au cadencement du processeur de la carte Arduino et permet d’obtenir, en utilisant la méthode ci-après présentée, un signal à 40 kHz pour les 64 transducteurs

### 2.2 Synchronisation

La synchronisation des deux cartes débute par un court protocole d’amorçage sur la liaison série. Avant tout échange automatique, la carte maître attend qu’un caractère (quelconque) soit envoyé depuis le moniteur série de l’utilisateur ; ce premier envoi agit comme un déclencheur manuel permettant de signaler que l’opérateur est prêt et que le système peut s’amorcer.

Lorsque ce caractère reçu, le maître transmet alors l’octet 0x55 à l’esclave. De son côté, l’esclave reste bloqué tant qu’il n’a pas reçu cette valeur, ce qui garantit qu’il ne démarre pas prématurément. Une fois 0x55 reconnu, l’esclave confirme implicitement sa disponibilité en allumant sa LED 13 et les deux cartes basculent dans leur boucle synchronisée.

À partir de ce point, l’horloge commune est fournie par le maître sous forme d’un signal carré de 80 kHz généré par le Timer 3. Chaque front descendant de ce signal, détecté sur INT5, incrémente sur les deux cartes le compteur sync_cnt, qui sert alors de référence temporelle partagée. Grâce à ce double mécanisme — déclenchement manuel, handshake maître-esclave via 0x55, puis synchronisation par horloge matérielle — les deux systèmes démarrent exactement en même temps et exécutent ensuite leurs mises à jour de sorties en parfaite simultanéité.

### 2.3 Emission

Une fois la synchronisation établie, les deux cartes peuvent commencer la phase d’émission. Chacune dispose d’un tableau buffer contenant les états logiques à appliquer successivement aux dix ports parallèles raccordés aux transducteurs. Ces valeurs représentent
les motifs d’excitation ultrasonore en haute résolution temporelle.

Lorsqu’un front descendant du signal de synchronisation est détecté, la fonction wait_ticks() assure que chaque mise à jour survient exactement au bon instant, garantissant un timing strictement identique entre le maître et l’esclave. À chaque tick, les cartes envoient simultanément les tranches successives du motif grâce à la macro OUTPUT_WAVE(), qui écrit en une seule instruction l’ensemble des dix octets sur les ports matériels.

L’organisation en pointeurs emittingPointerH et emittingPointerL permet de structurer les données en deux blocs correspondant aux étapes hautes et basses du motif. Ce mécanisme d’émission, basé sur l’écriture directe dans les registres et synchronisé par une horloge externe, assure une génération parfaitement alignée des ondes ultrasonores, condition indispensable pour obtenir un champ acoustique cohérent et stable.

## 3 Prise en main pratique

L’utilisation des deux Arduino n’étant pas à cette étape du projet optimale, il faut absolument veiller à réaliser les étapes suivantes dans l’ordre et en respectant précisément les recommandations à venir.

### 3.1 Téléversement des codes sur les 2 Arduino

La première étape consiste à téléverser les codes sur les 2 Arduino. Pour ce faire, il faut tout d’abord avoir repéré quel Arduino est connecté à quel port COM de l’ordinateur. Pour obtenir cette information, il suffit de connecter séparément chaque Arduino afin d’identifier à quel port il est associé. Une fois cette information obtenue, vous pouvez téléverser le code Arduino Maître sur l’Arduino contrôlant la plaque du bas et le code Esclave sur l’Arduino contrôlant la plaque du haut.

### 3.2 Connexion des deux Arduino

Il est maintenant temps de connecter l’Arduino maître (contrôlant la plaque du bas) à l’Arduino esclave (contrôlant la plaque du haut). Pour ce faire, il suffit de faire correspondre le connecteur mâle à 6 pins de la carte maître sur le connecteur femelle à 6 pins de la carte esclave en s’assurant que l’on connecte bien le port TX de la carte maître au port RX de la carte esclave (cf. gravures à l’arrière du PCB). Il est également possible d’utiliser un câble en nappe disposant de 6 connecteurs mâle et 6 connecteur femelle, ce qui permet d’augmenter la flexibilité de l’installation en réduisant les contraintes liées à la connexion des deux cartes. Cette solution est présentée en figure suivante.

Remarque : il est impossible de téléverser le code sur l’Arduino esclave lorsque ce dernier a été connecté à l’Arduino maître via son port RX car l’utilisation de ce dernier bloque l’accès à l’ordinateur au port série UART.

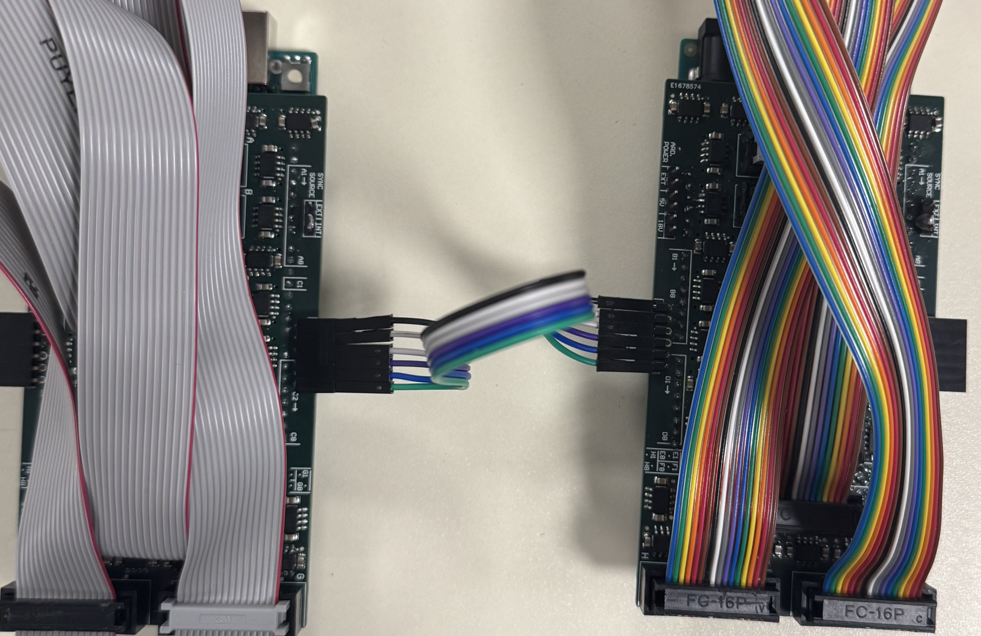
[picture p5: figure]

Figure 2 – Connexion physique des deux cartes Arduino

### 3.3 Lancement de l’émission sur les deux matrices

Une fois les connexions réalisées, il ne reste qu’à lancer l’émission des signaux acoustiques sur les 2 matrices de 64 transducteurs. Pour cela, il suffit d’envoyer via le moniteur série de l’Arduino maître un caractère quelconque (lettre ou chiffre) à l’Arduino esclave. L’envoi de ce caractère permet de synchroniser les 2 Arduino et d’initier l’émission des signaux.

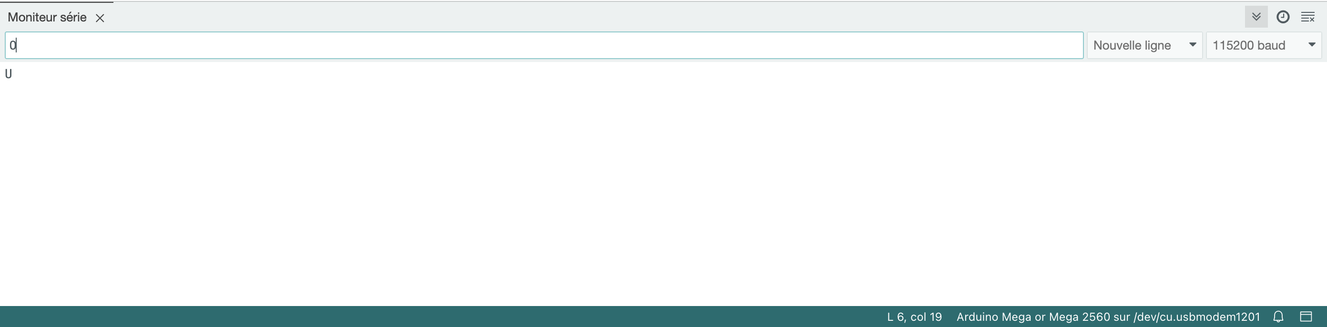
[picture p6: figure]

Figure 3 – Interface du moniteur série pour l’initialisation

### 3.4 Alimentation du dispositif

L’étape finale consiste à alimenter le dispositif avec une tension continue comprise entre 25 et 35 Vpp.

Pour cela, connecter d’abord les fiches banane noire et rouge du câble d’alimentation respectivement sur la borne et la borne + de l’alimentation continue.

Ensuite, connecter la fiche jack du câble d’alimentation à l’un des deux shield d’amplification (maître ou esclave, les deux étant interconnectés). Pour cette étape, se référer au paragraphe "Alimentation du Driver Board" de la notice d’utilisation du prototype à une plaque disponible sur notre GitHub. (https://github.com/simoradiakram-star/Projet-Levitation-acoustique) Enfin, allumer l’alimentation, régler l’intensité environ au tiers du maximum et enfin régler la tension à environ 25 V.

Remarque : par expérience, il est possible qu’un court-circuit apparaisse à la suite d’une mauvaise manipulation du matériel. Ce dernier est souvent repérable à l’aide de l’alimentation continue : si le voyant “CC” de cette dernière est allumé ou l’on entend les calibres de cette dernière passer les uns à la suite des autres, l’éteindre immédiatement afin de préserver le matériel.

Il ne reste plus qu’à faire léviter !

### 3.5 Procédure d’arrêt

Pour éteindre le système, il suffit de commencer par éteindre l’alimentation continue, puis de déconnecter les Arduino de l’ordinateur.

## A Annexes techniques

A.1 | Communication à deux cartes Arduino
A.1.1 | Carte maître

Voici le code Arduino utilisé pour le contrôle de la carte maître :

1 | # include < avr / sleep .h >
2 | # include < avr / power .h >

3
4 | # define N_PATTERNS 32
5 | # define N_TRANSDUCTEUR 80
6 | # define N_PORTS 10
7 | # define N_DIVS 10
8 | # define N_T 8

9
10 // ports A C L B K F H D G J

11
12 # define WAIT () __asm__ __volatile__ (" nop \n\t""nop \n\t"" nop \n\t"" nop \n\t"" nop \n\t"" nop\n\t "" nop \n\t"" nop\n\t""nop \n\t"" nop \n\t")
13 | # define OUTPUT_WAVE ( pointer , d ) | PORTA = pointer [d* N_PORTS + 0]; PORTC = pointer [d *
N_PORTS + 1]; PORTL = pointer [d* N_PORTS + 2]; PORTB = pointer [ d* N_PORTS + 3]; PORTK = pointer [d* N_PORTS + 4]; PORTF = pointer [ d* N_PORTS + 5]; PORTH = pointer [d* N_PORTS + 6]; PORTD = pointer [d* N_PORTS + 7]; PORTG = pointer [ d* N_PORTS + 8]; PORTJ = pointer [ d* N_PORTS + 9]

14
15 | static byte buffer [ N_DIVS * N_PORTS ];
16 | volatile uint8_t sync_cnt = 0; | // compteur de fronts sur pin 3 ( INT5 )

17
18 | // Attente robuste de N ticks ( gere le wrap 0..255 et les ticks manques )
19 | static inline void wait_ticks ( uint8_t n , volatile uint8_t * last_seen ) {
20 | uint8_t start = * last_seen ;
21 | while ( ( uint8_t )( sync_cnt - start ) < n ) { /* spin , interruptions actives */ }
22 | * last_seen = sync_cnt ;
23 | }

24
25 | static inline void wait_substep ( volatile uint16_t * tref , uint16_t ticks )
26 | {
27 | uint16_t start = * tref ;
28 | while (( uint16_t )( TCNT4 - start ) < ticks ) {
29 | // attente active , base de temps = Timer4
30 | }
31 | * tref = start + ticks ;
32 | }

33
34 | void setup ()
35 | {
36 | // set as output ports A C L B K F H D G J
37 | DDRA = DDRC = DDRL = DDRB = DDRK = DDRF = DDRH = DDRD = DDRG = DDRJ = 0 xFF ;
38 | // low signal on all of them
39 | PORTA = PORTC = PORTL = PORTB = PORTK = PORTF = PORTH = PORTD = PORTG = PORTJ = 0 x00 ;

40
41 | // clear the buffers
42 | for ( int i = 0; i < ( N_PATTERNS * N_DIVS * N_PORTS ) ; ++ i) {
43 | buffer [i] = 0;
44 | }

45
46 | // INT5 ( PE5 = pin 3 sur Mega ) sur FRONT DESCENDANT
47 | EICRB |= (1 << ISC51 ); | // ISC51 :50 = 10 = > front descendant
48 | EICRB &= ~(1 << ISC50 ) ;
49 | EIFR | = (1 << INTF5 ) ; | // clear tout pending
50 | EIMSK |= (1 << INT5 ); | // enable INT5

51
52 | // generate a sync signal of 40 khz in pin 2
53 | pinMode (2 , OUTPUT ) ;
54 | noInterrupts () ; | // disable all interrupts
55 | TCCR3A = bit ( WGM10 ) | bit ( WGM11 ) | bit ( COM1B1 ); // fast PWM , clear OC1B on compare
56 | TCCR3B = bit ( WGM12 ) | bit ( WGM13 ) | bit ( CS10 ); | // fast PWM , no prescaler
57 | OCR3A = | ( F_CPU / 80000 L) - 1;
58 | OCR3B = ( F_CPU / 80000 L) / 2;

59 | TCCR4A =0;
60 | TCCR4B =(1 < < CS40 ) ;
61 | TCNT4 =0;

62
63 | interrupts () ; | // enable all interrupts

64
65 | // sync in signal at pin 3
66 | pinMode (3 , INPUT_PULLUP ); // please connect pin3 to pin 2

67
68
69 | // disable everything that we do not need
70 | ADCSRA = 0; | // ADC
71 | power_adc_disable () ;
72 | power_spi_disable () ;
73 | power_twi_disable () ;
74 | power_timer0_disable () ;
75 | power_usart1_disable () ;
76 | power_usart2_disable () ;
77 | power_usart3_disable () ;

78
79 | // creation d’une liste de valeur binaire
80 | byte buffer [ N_DIVS * N_PORTS ] = {
81 | 0 xFF , 0 xFF , 0 xFF , 0 xFF , 0 xFF , 0 xFF , 0 x7B , 0 x8F , 0 x07 , 0 x03 ,
82 | 0 xFF , 0 xFF , 0 xFF , 0 xFF , 0 xFF , 0 xFF , 0 x7B , 0 x8F , 0 x07 , 0 x03 ,
83 | 0 xFF , 0 xFF , 0 xFF , 0 xFF , 0 xFF , 0 xFF , 0 x7B , 0 x8F , 0 x07 , 0 x03 ,
84 | 0 xFF , 0 xFF , 0 xFF , 0 xFF , 0 xFF , 0 xFF , 0 x7B , 0 x8F , 0 x07 , 0 x03 ,
85 | 0 x42 , 0 x32 , 0 xCB , 0 x4D , 0 x5A , 0 xBD , 0 x10 , 0 x82 , 0 x00 , 0 x01 ,
86 | 0 x00 , 0 x00 , 0 x00 , 0 x00 , 0 x00 , 0 x00 , 0 x00 , 0 x00 , 0 x00 , 0 x00 ,
87 | 0 x00 , 0 x00 , 0 x00 , 0 x00 , 0 x00 , 0 x00 , 0 x00 , 0 x00 , 0 x00 , 0 x00 ,
88 | 0 x00 , 0 x00 , 0 x00 , 0 x00 , 0 x00 , 0 x00 , 0 x00 , 0 x00 , 0 x00 , 0 x00 ,
89 | 0 x00 , 0 x00 , 0 x00 , 0 x00 , 0 x00 , 0 x00 , 0 x00 , 0 x00 , 0 x00 , 0 x00 ,
90 | 0 xBD , 0 xCD , 0 x34 , 0 xB2 , 0 xA5 , 0 x42 , 0 x6B , 0 x0D , 0 x07 , 0 x02
91 | };

92
93
94 | // initialisation des variables
95 | byte * emittingPointerH = & buffer [0];
96 | byte * emittingPointerL = & buffer [ N_PORTS * N_DIVS / 2];

97
98 | Serial . begin (115200) ;
99 | while (! Serial . available () );
100 | Serial . write (0 x55 );

101
102
103 // ------boucle - ---- ---- ---- ---- ---- ---

104
105 | LOOP :
106 | {
107 | uint8_t last = sync_cnt ;

108
109 | wait_ticks (1 ,& last );
110 | OUTPUT_WAVE ( emittingPointerH , 0) ; WAIT () ;
111 | OUTPUT_WAVE ( emittingPointerH , 1) ; WAIT () ;
112 | OUTPUT_WAVE ( emittingPointerH , 2) ; WAIT () ;
113 | OUTPUT_WAVE ( emittingPointerH , 3) ; WAIT () ;
114 | OUTPUT_WAVE ( emittingPointerH , 4) ; WAIT () ;
115 | OUTPUT_WAVE ( emittingPointerL , 0) ; WAIT () ;
116 | OUTPUT_WAVE ( emittingPointerL , 1) ; WAIT () ;
117 | OUTPUT_WAVE ( emittingPointerL , 2) ; WAIT () ;
118 | OUTPUT_WAVE ( emittingPointerL , 3) ; WAIT () ;
119 | OUTPUT_WAVE ( emittingPointerL , 4) ; WAIT () ;

120
121
122 | goto LOOP ;
123 | }
124 | }

125
126 void loop () {}

127
128 | ISR ( INT5_vect ) {
129 | sync_cnt ++;
130 | }

A.1.2 Carte esclave

De même, voici le code Arduino utilisé pour le contrôle de la carte esclave :

1 | # include < avr / sleep .h >
2 | # include < avr / power .h >

3
4 | # define N_PATTERNS 32
5 | # define N_TRANSDUCTEUR 80
6 | # define N_PORTS 10
7 | # define N_DIVS 10
8 | # define N_T 8

9
10 # define WAIT () __asm__ __volatile__ (" nop \n\t""nop \n\t"" nop \n\t"" nop \n\t"" nop \n\t"" nop\n\t "" nop \n\t"" nop\n\t""nop \n\t"" nop \n\t")
11 | # define OUTPUT_WAVE ( pointer , d ) | PORTA = pointer [d* N_PORTS + 0]; PORTC = pointer [d *
N_PORTS + 1]; PORTL = pointer [d* N_PORTS + 2]; PORTB = pointer [ d* N_PORTS + 3]; PORTK = pointer [d* N_PORTS + 4]; PORTF = pointer [ d* N_PORTS + 5]; PORTH = pointer [d* N_PORTS + 6]; PORTD = pointer [d* N_PORTS + 7]; PORTG = pointer [ d* N_PORTS + 8]; PORTJ = pointer [ d* N_PORTS + 9]

12
13 | static byte buffer [ N_DIVS * N_PORTS ];
14 | volatile uint8_t sync_cnt = 0;

15
16 | static inline void wait_ticks ( uint8_t n , volatile uint8_t * last_seen ) {
17 | uint8_t start = * last_seen ;
18 | while ( ( uint8_t )( sync_cnt - start ) < n ) { }
19 | * last_seen = sync_cnt ;
20 | }

21
22 | void setup ()
23 | {
24 | DDRA = DDRC = DDRL = DDRB = DDRK = DDRF = DDRH = DDRD = DDRG = DDRJ = 0 xFF ;
25 | PORTA = PORTC = PORTL = PORTB = PORTK = PORTF = PORTH = PORTD = PORTG = PORTJ = 0 x00 ;

26
27 for ( int i = 0; i < ( N_PATTERNS * N_DIVS * N_PORTS ) ; ++ i) { buffer [i] = 0; }

28
29 | EICRB |= (1 << ISC51 ); EICRB &= ~(1 << ISC50 );
30 | EIFR | = (1 << INTF5 ) ; EIMSK |= (1 << INT5 ) ;
31 | pinMode (3 , INPUT_PULLUP );

32
33 | ADCSRA = 0; power_adc_disable () ; power_spi_disable () ; power_twi_disable () ;
34 | power_timer0_disable () ; power_usart1_disable () ; power_usart2_disable () ;
power_usart3_disable () ;

35
36 | byte buffer [ N_DIVS * N_PORTS ] = {
37 | 0 xFF , 0 xFF , 0 xFF , 0 xFF , 0 xFF , 0 xFF , 0 x7B , 0 x8F , 0 x07 , 0 x03 ,
38 | 0 xFF , 0 xFF , 0 xFF , 0 xFF , 0 xFF , 0 xFF , 0 x7B , 0 x8F , 0 x07 , 0 x03 ,
39 | 0 xFF , 0 xFF , 0 xFF , 0 xFF , 0 xFF , 0 xFF , 0 x7B , 0 x8F , 0 x07 , 0 x03 ,
40 | 0 xFF , 0 xFF , 0 xFF , 0 xFF , 0 xFF , 0 xFF , 0 x7B , 0 x8F , 0 x07 , 0 x03 ,
41 | 0 xBD , 0 xCD , 0 x34 , 0 xB2 , 0 xA5 , 0 x42 , 0 x6B , 0 x0D , 0 x07 , 0 x02 ,
42 | 0 x00 , 0 x00 , 0 x00 , 0 x00 , 0 x00 , 0 x00 , 0 x00 , 0 x00 , 0 x00 , 0 x00 ,
43 | 0 x00 , 0 x00 , 0 x00 , 0 x00 , 0 x00 , 0 x00 , 0 x00 , 0 x00 , 0 x00 , 0 x00 ,
44 | 0 x00 , 0 x00 , 0 x00 , 0 x00 , 0 x00 , 0 x00 , 0 x00 , 0 x00 , 0 x00 , 0 x00 ,
45 | 0 x00 , 0 x00 , 0 x00 , 0 x00 , 0 x00 , 0 x00 , 0 x00 , 0 x00 , 0 x00 , 0 x00 ,
46 | 0 x42 , 0 x32 , 0 xCB , 0 x4D , 0 x5A , 0 xBD , 0 x10 , 0 x82 , 0 x00 , 0 x01
47 | };

48
49 | byte * emittingPointerH = & buffer [0];
50 | byte * emittingPointerL = & buffer [ N_PORTS * N_DIVS / 2];
51 | pinMode (13 , OUTPUT );
52 | Serial . begin (115200) ;
53 | while (! Serial . available () );
54 | while ( Serial . read () !=0 x55 );
55 | digitalWrite (13 , HIGH );

56
57 | LOOP :
58 | {
59 | uint8_t last = sync_cnt ;
60 | wait_ticks (1 ,& last );
61 | OUTPUT_WAVE ( emittingPointerH , 0) ; WAIT () ;
62 | OUTPUT_WAVE ( emittingPointerH , 1) ; WAIT () ;
63 | OUTPUT_WAVE ( emittingPointerH , 2) ; WAIT () ;

64 | OUTPUT_WAVE ( emittingPointerH , 3) ; WAIT () ;
65 | OUTPUT_WAVE ( emittingPointerH , 4) ; WAIT () ;
66 | OUTPUT_WAVE ( emittingPointerL , 0) ; WAIT () ;
67 | OUTPUT_WAVE ( emittingPointerL , 1) ; WAIT () ;
68 | OUTPUT_WAVE ( emittingPointerL , 2) ; WAIT () ;
69 | OUTPUT_WAVE ( emittingPointerL , 3) ; WAIT () ;
70 | OUTPUT_WAVE ( emittingPointerL , 4) ; WAIT () ;
71 | goto LOOP ;
72 | }
73 | }
74 | void loop () {}
75 | ISR ( INT5_vect ) { sync_cnt ++; }

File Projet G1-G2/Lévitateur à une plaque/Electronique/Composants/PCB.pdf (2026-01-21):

## HQDFM Design for Manufacture(DFM) Report

### File name: 0000A328399_1

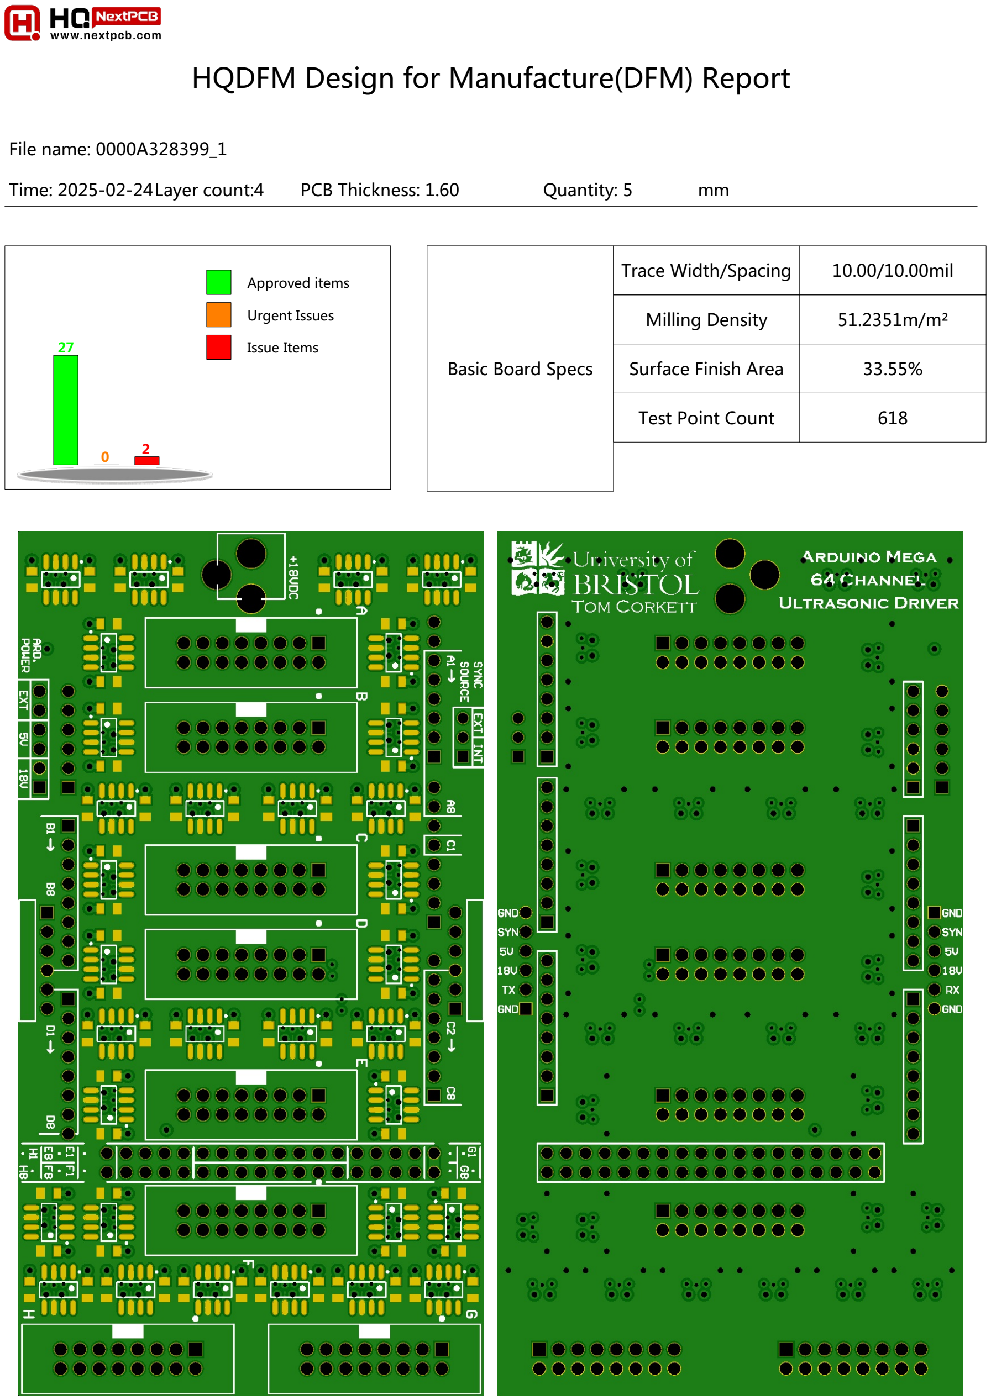
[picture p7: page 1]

Time: 2025-02-24Layer count:4 | PCB Thickness: 1.60 | Quantity: 5
mm

Approved items

Urgent Issues

### 27 Issue Items

0

2

Basic Board Specs

Trace Width/Spacing | 10.00/10.00mil
Milling Density | 51.2351m/m²
Surface Finish Area | 33.55%
Test Point Count | 618

Type | Category | No. of Checks | Result
| Open/Shorts (IPC) | 1 | Fail
| Signal Integrity | 4 | Pass
| Smallest Trace Width | 1 | Pass 3
| Smallest Trace Spacing | 3 | Pass 131
| SMD Pad Spacing | 1 | Pass
| Pad Size | 3 | Pass 4
| Hatched Copper Pour | 2 | Pass
| Annular Ring Size | 2 | Pass 4
| Drill to Copper | 5 | Pass 1023
| Copper-to-Board Edge | 2 | Pass 1 , Fail 8
| Holes on SMD Pads | 4 | Pass
PCB Drilling Analysis | Drill Diameter | 8 | Pass 24
| Drill Hole Density | 1 | Pass
| Drill Diameter | 8 | Pass 24
| Drill Spacing | 4 | Pass 96
| Drill to Board Edge | 4 | Pass
| Drill Hole Density | 1 | Pass
| Special Drill Holes | 2 | Pass
| Drill Hole Errors | 3 | Pass
PCB Solder Mask Analysis | Solder Mask Dam | 2 | Pass
| Missing SMask Opening | 1 | Pass
| Solder Paste Area | 1 | Pass
PCB Silk Analysis | Silkscreen Spacing | 1 | Pass
PCBA Fiducial Analysis | Fiducial Count | 1 | Fail

PCB Trace Analysis

ID

C

h

eck | Limits | V

### alu

e | Issu
e | Im
a

g

e

P

### ositio

n

## Qty Le

v

el 1 | Copper-to- Board Edge_Cop per-to- Board Edge | 8,15,20 | 0.00 mm | For most factories, the copper-to-board edge clearance requirement is 0.2 mm. Failure to meet the factory's requirements could increase the risk of exposed copper on the edge of the boards or damaged traces/pads, which decrease manufacturing efficiency and yield, and affect the reliability of the boards. Copper-to-board edge spacing of 0.00mil was detected in your design. It is recommended to increase the spacing to at least 0.25 mm for edge routing and 0.4 mm for v- cuts (v-cut spacing may depends on board thickness). | 0.00,114.05 | 4 | Risk

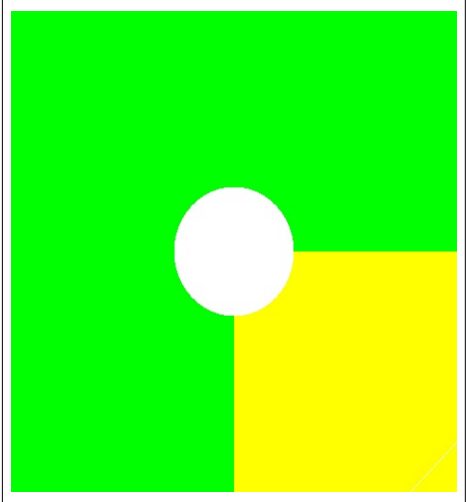
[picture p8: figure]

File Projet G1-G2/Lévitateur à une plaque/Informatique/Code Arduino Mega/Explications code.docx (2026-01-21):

# Code en Java

package acousticfield3d.protocols;

import acousticfield3d.gui.MainForm;

import acousticfield3d.math.M;

import acousticfield3d.simulation.AnimKeyFrame;

import acousticfield3d.simulation.TransState;

import acousticfield3d.simulation.Transducer;

import acousticfield3d.utils.ArrayUtils;

import acousticfield3d.utils.TextFrame;

import java.util.ArrayList;

import java.util.HashMap;

import java.util.List;

/**

*

* @author am14010

*/

public class ArduinoMEGA64 extends ArduinoNano{

final static byte COMMAND_COMMIT_DURATIONS = 0x10;

@Override

public int getDivs() {

return 10;

}

@Override

public int getSpeed() {

return 115200;

}

public int getNPorts() {

return 10;

}

public int getSignalsPerBoard(){

return 64;

}

public byte[] calcDataBytes(final AnimKeyFrame key) {

//TODO refactor this shameful repetition of code

final int nTrans = Transducer.getMaxPin(key.getTransAmplitudes().keySet()) + 1;

final int signalsPerBoard = getSignalsPerBoard();

final int nBoards = (nTrans - 1) / signalsPerBoard + 1;

assert (nBoards < 15);

final int nDivs = getDivs();

final int nPorts = getNPorts();

final int bytesPerBoard = nDivs * nPorts;

byte[] data = new byte[nBoards * bytesPerBoard];

for ( Transducer t : key.getTransAmplitudes().keySet() ) {

final int n = t.getDriverPinNumber();

if (n >= 0) {

final float amplitude = key.getTransAmplitudes().get(t);

final float fphase = key.getTransPhases().get(t);

final int board = n / signalsPerBoard;

final int softwarePin = n % signalsPerBoard;

final int hardwarePin = PORT_MAPPING[softwarePin];

final int phaseCompensation = PHASE_COMPENSATION[softwarePin];

final int targetByte = hardwarePin / 8;

final byte value = (byte) ((1 << (hardwarePin % 8)) & 0xFF);

final int phase = Transducer.calcDiscPhase(fphase + t.getPhaseCorrection(), nDivs);

//TODO the divs to amplitude is not going to be linear but it will do for the moment

final int ampDivs = M.iclamp(Math.round(amplitude * nDivs / 2), 0, nDivs);

for (int i = 0; i < ampDivs; ++i) {

final int d = (i + phase + phaseCompensation) % nDivs;

data[board * bytesPerBoard + targetByte + d * nDivs] |= value;

}

}

}

return data;

}

@Override

public void sendAnim(final List<AnimKeyFrame> keyFrames) {

if(serial == null){

return;

}

//send patterns

final List<AnimKeyFrame> frames = keyFrames;

final ArrayList<Integer> durations = new ArrayList<>();

for (AnimKeyFrame k : frames) {

final float duration = k.getDuration();

//if (duration > 0.0f){

durations.add((int) duration);

final AnimKeyFrame akf = k;

final int nTrans = Transducer.getMaxPin(k.getTransAmplitudes().keySet()) + 1;

final int signalsPerBoard = getSignalsPerBoard();

final int nBoards = (nTrans - 1) / signalsPerBoard + 1;

assert (nBoards < 15);

final int nDivs = getDivs();

final int nPorts = getNPorts();

final int bytesPerBoard = nDivs * nPorts;

byte[] data = calcDataBytes(k);

for (int i = 0; i < nBoards; ++i) {

for (int j = 0; j < bytesPerBoard; ++j) {

int dataIndex = i * bytesPerBoard + j;

serial.writeByte((data[dataIndex] & 0xF0) | (i + 1));

serial.writeByte(((data[dataIndex] << 4) & 0xF0) | (i + 1));

}

}

}

//send durations

durations.add(0); //stop frame

sendDurations( ArrayUtils.toArray(durations) );

}

@Override

public void sendPattern(final List<Transducer> transducers) {

if(serial == null){

return;

}

final int nTrans = Transducer.getMaxPin(transducers) + 1;

final int signalsPerBoard = getSignalsPerBoard();

final int nBoards = (nTrans-1) / signalsPerBoard + 1;

if (nBoards >= 15){

//TODO log error

return;

}

final int nDivs = getDivs();

final int nPorts = getNPorts();

final int bytesPerBoard = nDivs * nPorts;

byte[] data = new byte[nBoards * bytesPerBoard];

for(Transducer t : transducers){

final int n = t.getDriverPinNumber();

if(n >= 0){

final int board = n / signalsPerBoard;

final int softwarePin = n % signalsPerBoard;

final int hardwarePin = PORT_MAPPING[softwarePin];

final int phaseCompensation = PHASE_COMPENSATION[softwarePin];

final int targetByte = hardwarePin / 8;

final byte value = (byte)((1 << (hardwarePin % 8)) & 0xFF);

final int phase = Transducer.calcDiscPhase(t.getPhase() + t.getPhaseCorrection(), nDivs);

//TODO the divs to amplitude is not going to be linear but it will do for the moment

final int ampDivs = M.iclamp(Math.round(t.getpAmplitude() * nDivs / 2), 0, nDivs);

for (int i = 0; i < ampDivs; ++i) {

final int d = (i + phase + phaseCompensation) % nDivs;

data[board*bytesPerBoard + targetByte + d * nDivs] |= value;

}

}

}

for(int i = 0; i < nBoards; ++i){

for(int j = 0; j < bytesPerBoard; ++j){

int dataIndex = i*bytesPerBoard + j;

serial.writeByte( (data[dataIndex] & 0xF0) | (i+1) );

serial.writeByte( ((data[dataIndex] << 4) & 0xF0) | (i+1) );

}

}

sendDurations( new int[]{1,0} );

}

@Override

public void sendDurations(final int[] durations){

final int n = durations.length;

final int COMMAND = (byte)0x30; //XX110000

//(bReceived & 0x11000000) >> (durationsWrittingIndex % 4 * 2)

for(int i = 0; i < n; ++i){

final int d = durations[i];

serial.writeByte( COMMAND | ((d << 0) & 0xC0) );

serial.writeByte( COMMAND | ((d << 2) & 0xC0) );

serial.writeByte( COMMAND | ((d << 4) & 0xC0) );

serial.writeByte( COMMAND | ((d << 6) & 0xC0) );

}

//commit durations

serial.writeByte( COMMAND_COMMIT_DURATIONS );

serial.flush();

}

//sorry, repeated code everywhere

public static void exportAnimation(MainForm mf) {

final List<AnimKeyFrame> frames = mf.animPanel.getCurrentAnimation().getKeyFrames().getElements();

ArduinoMEGA64 ins = new ArduinoMEGA64();

final StringBuilder sb = new StringBuilder();

sb.append("{");

final int nKeys = frames.size();

int ik = 0;

for (AnimKeyFrame k : frames) {

final byte[] data = ins.calcDataBytes( k );

final int l = data.length;

for (int in = 0; in < l; ++in) {

sb.append("0x" + Integer.toHexString(data[in] & 0xFF));

if (in != l - 1) {

sb.append(",");

}

}

if (ik != nKeys - 1) {

sb.append("},\n");

} else {

sb.append("}}");

}

++ik;

}

TextFrame.showText("Animation Data", sb.toString(), mf);

}

public static final int[] PORT_MAPPING = {51, 52, 53, 54, 28, 29, 30, 31, 47, 46, 45, 44, 43, 42, 41, 40, 56, 57, 58, 59, 48, 49, 72, 69, 39, 38, 37, 36, 35, 34, 33, 32, 21, 23, 65, 63, 9, 11, 13, 15, 20, 22, 64, 66, 8, 10, 12, 14, 24, 25, 26, 27, 16, 17, 18, 19, 7, 6, 5, 4, 3, 2, 1, 0};

//public static final int[] PHASE_COMPENSATION = {0, 0, 0, 0, 1, 1, 1, 1, 1, 1, 1, 1, 1, 1, 1, 1, 0, 0, 0, 0, 0, 0, 0, 0, 1, 1, 1, 1, 1, 1, 1, 1, 1, 1, 0, 0, 1, 1, 1, 1, 1, 1, 0, 0, 1, 1, 1, 1, 1, 1, 1, 1, 1, 1, 1, 1, 1, 1, 1, 1, 1, 1, 1, 1};

public static final int[] PHASE_COMPENSATION = {0, 0, 0, 0, 0, 0, 0, 0, 0, 0, 0, 0, 0, 0, 0, 0, 0, 0, 0, 0, 0, 0, 0, 0, 0, 0, 0, 0, 0, 0, 0, 0, 0, 0, 0, 0, 0, 0, 0, 0, 0, 0, 0, 0, 0, 0, 0, 0, 0, 0, 0, 0, 0, 0, 0, 0, 0, 0, 0, 0, 0, 0, 0, 0};

}

# Explication code

Voici une explication détaillée du programme ArduinoMEGA64. Ce programme fait partie du projet acousticfield3d, qui semble être un logiciel de simulation et de contrôle de champs acoustiques en 3D.

## 1️⃣ Présentation générale

Le fichier ArduinoMEGA64.java définit une classe qui hérite de ArduinoNano. Cette classe est utilisée pour interfacer un microcontrôleur Arduino Mega avec 64 sorties afin de contrôler des transducteurs ultrasoniques. Son but principal est d'envoyer des signaux précis aux transducteurs pour générer des champs acoustiques spécifiques.

## 2️⃣ Les imports

import acousticfield3d.gui.MainForm;

import acousticfield3d.math.M;

import acousticfield3d.simulation.AnimKeyFrame;

import acousticfield3d.simulation.TransState;

import acousticfield3d.simulation.Transducer;

import acousticfield3d.utils.ArrayUtils;

import acousticfield3d.utils.TextFrame;

import java.util.ArrayList;

import java.util.HashMap;

import java.util.List;

- acousticfield3d.gui.MainForm : Interface utilisateur principale.
- acousticfield3d.math.M : Classe contenant des opérations mathématiques.
- acousticfield3d.simulation.AnimKeyFrame : Représente une image clé d’animation.
- acousticfield3d.simulation.TransState : État des transducteurs à un moment donné.
- acousticfield3d.simulation.Transducer : Représente un transducteur.
- acousticfield3d.utils.ArrayUtils : Utilitaires pour manipuler des tableaux.
- acousticfield3d.utils.TextFrame : Gestion de l'affichage des textes.

## 3️⃣ Définition de la classe et constantes

public class ArduinoMEGA64 extends ArduinoNano {

final static byte COMMAND_COMMIT_DURATIONS = 0x10;

- ArduinoMEGA64 hérite de ArduinoNano, ce qui signifie qu'elle étend les fonctionnalités d’une classe qui gère probablement les commandes de base d’un microcontrôleur.
- COMMAND_COMMIT_DURATIONS : Une constante définissant une commande (0x10) envoyée au microcontrôleur pour valider les durées des signaux.

## 4️⃣ Méthodes de configuration du matériel

Ces méthodes définissent certaines caractéristiques du matériel :

@Override

public int getDivs() {

return 10;

}

@Override

public int getSpeed() {

return 115200;

}

public int getNPorts() {

return 10;

}

public int getSignalsPerBoard() {

return 64;

}

- getDivs() : Nombre de divisions pour moduler les signaux des transducteurs.
- getSpeed() : Vitesse de communication série (baud rate) avec l’Arduino.
- getNPorts() : Nombre de ports utilisés pour piloter les transducteurs.
- getSignalsPerBoard() : Nombre de signaux pouvant être gérés par une carte (64 pour l'Arduino Mega).

## 5️⃣ Génération des données pour le microcontrôleur

public byte[] calcDataBytes(final AnimKeyFrame key) {

Cette méthode génère les données binaires à envoyer à l'Arduino en fonction de l’image clé d’animation (AnimKeyFrame).

#### ⚡ Déroulé du traitement

Calcul du nombre de transducteurs actifs

final int nTrans = Transducer.getMaxPin(key.getTransAmplitudes().keySet()) + 1;

  - Récupère le numéro de pin le plus élevé parmi les transducteurs actifs.

Calcul du nombre de cartes nécessaires

final int signalsPerBoard = getSignalsPerBoard();

final int nBoards = (nTrans - 1) / signalsPerBoard + 1;

assert (nBoards < 15);

  - Chaque carte peut gérer 64 transducteurs.
  - Vérification qu’on ne dépasse pas 15 cartes.

Initialisation des paramètres

final int nDivs = getDivs();

final int nPorts = getNPorts();

final int bytesPerBoard = nDivs * nPorts;

byte[] data = new byte[nBoards * bytesPerBoard];

Traitement des transducteurs

for (Transducer t : key.getTransAmplitudes().keySet()) {

  - Pour chaque transducteur, récupération des amplitudes et phases.

Mapping des pins et phase correction

final int hardwarePin = PORT_MAPPING[softwarePin];

final int phaseCompensation = PHASE_COMPENSATION[softwarePin];

  - Utilise des tables de conversion pour attribuer les bonnes connexions physiques.

Génération du signal modulé

final int phase = Transducer.calcDiscPhase(fphase + t.getPhaseCorrection(), nDivs);

final int ampDivs = M.iclamp(Math.round(amplitude * nDivs / 2), 0, nDivs);

  - Convertit la phase en valeur discrète.
  - L’amplitude est limitée à la plage autorisée.

Stockage des données dans le tableau data[]

for (int i = 0; i < ampDivs; ++i) {

final int d = (i + phase + phaseCompensation) % nDivs;

data[board * bytesPerBoard + targetByte + d * nDivs] |= value;

}

  - Stocke les valeurs dans le tableau de données binaires.

## 6️⃣ Envoi des animations

@Override

public void sendAnim(final List<AnimKeyFrame> keyFrames) {

Cette méthode envoie les animations complètes à l’Arduino.

Vérification de la connexion série

if(serial == null) { return; }

Préparation des données

final List<AnimKeyFrame> frames = keyFrames;

final ArrayList<Integer> durations = new ArrayList<>();

Envoi des données de chaque image clé

for (AnimKeyFrame k : frames) {

byte[] data = calcDataBytes(k);

for (int i = 0; i < nBoards; ++i) {

for (int j = 0; j < bytesPerBoard; ++j) {

serial.writeByte((data[dataIndex] & 0xF0) | (i + 1));

serial.writeByte(((data[dataIndex] << 4) & 0xF0) | (i + 1));

}

}

}

Envoi des durées

sendDurations(ArrayUtils.toArray(durations));

## 7️⃣ Envoi des motifs statiques

@Override

public void sendPattern(final List<Transducer> transducers) {

Cette méthode envoie un état statique des transducteurs à l’Arduino.

## 8️⃣ Envoi des durées

@Override

public void sendDurations(final int[] durations) {

Cette méthode envoie les durées des animations au microcontrôleur.

## 9️⃣ Exportation des animations

public static void exportAnimation(MainForm mf) {

- Exporte les données d’animation sous forme d’un texte lisible.
- Utile pour déboguer ou analyser les signaux envoyés.

## 🔟 Constantes de mappage des ports

public static final int[] PORT_MAPPING = { ... };

public static final int[] PHASE_COMPENSATION = { ... };

- PORT_MAPPING : Associe les broches logicielles aux broches physiques.
- PHASE_COMPENSATION : Compense les erreurs de phase des transducteurs.

## 📝 Conclusion

Ce programme est un pilote logiciel permettant de contrôler un réseau de transducteurs ultrasoniques via un Arduino Mega. Il génère et envoie des signaux précis pour créer des champs acoustiques dynamiques ou statiques.

# Onglet 3

QUESTION Peux-tu me citer toutes les fonctions du code en java en les répartissant par dossier comme elles sont ?

J'ai extrait la structure du projet et identifié plusieurs fichiers Java dans AcousticFieldSim.

Le code est organisé en plusieurs dossiers :

### 1. GUI (Interface graphique)

- acousticfield3d/gui/SimulationConfigForm.java
- acousticfield3d/gui/AddTransducersForm.java
- acousticfield3d/gui/misc/SliderPanel.java
- acousticfield3d/gui/misc/ExportPlotsForm.java
- acousticfield3d/gui/misc/ForcePlotsFrame.java
- acousticfield3d/gui/panels/TransducersPanel.java
- acousticfield3d/gui/panels/TrapsPanel.java
- acousticfield3d/gui/panels/AnimPanel.java
- acousticfield3d/gui/panels/TransControlPanel.java

📌 Responsabilité : Ces fichiers gèrent l'affichage, la configuration et les interactions avec l'utilisateur.

### 2. Simulation et Modélisation

- acousticfield3d/simulation/Simulation.java
- acousticfield3d/simulation/Trap.java
- acousticfield3d/simulation/Transducer.java
- acousticfield3d/simulation/Slice.java
- acousticfield3d/simulation/ControlPoint.java

📌 Responsabilité : Ces fichiers modélisent le comportement des transducteurs et des champs acoustiques.

### 3. Algorithmes de calcul du champ acoustique

- acousticfield3d/algorithms/SliceCalculation.java
- acousticfield3d/algorithms/Kinoforms.java
- acousticfield3d/algorithms/CalcField.java
- acousticfield3d/algorithms/SimplePhaseAlgorithms.java
- acousticfield3d/algorithms/BFGSOptimization.java

📌 Responsabilité : Ces fichiers contiennent les calculs mathématiques pour générer et simuler les ondes ultrasoniques.

### 4. Gestion de la communication avec l'Arduino

- acousticfield3d/protocols/ArduinoNano.java
- acousticfield3d/protocols/ArduinoMEGA64.java
- acousticfield3d/protocols/DeviceConnection.java

📌 Responsabilité : Envoi des phases et amplitudes aux transducteurs via l'Arduino Mega.

### 5. Rendu graphique 3D

- acousticfield3d/renderer/Shader.java
- acousticfield3d/renderer/Texture.java
- acousticfield3d/renderer/Renderer.java

📌 Responsabilité : Affichage des champs acoustiques en 3D avec OpenGL.

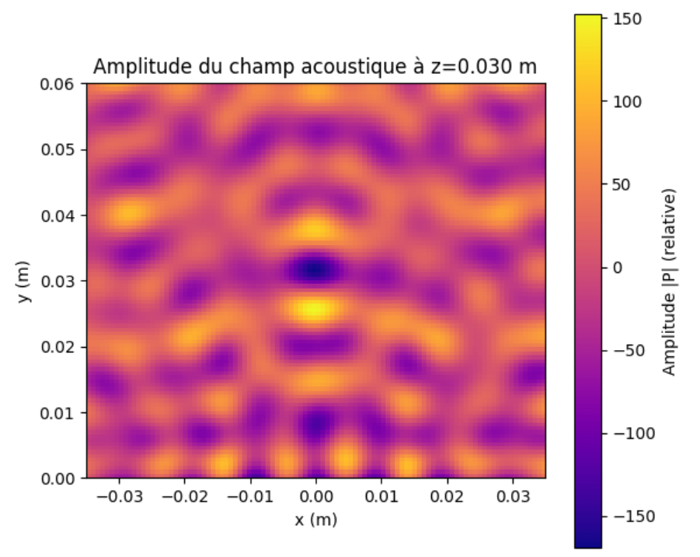
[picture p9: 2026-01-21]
Projet G1-G2/Lévitateur à une plaque/Physique théorique/Photos/vortex 2 plaque (3).png

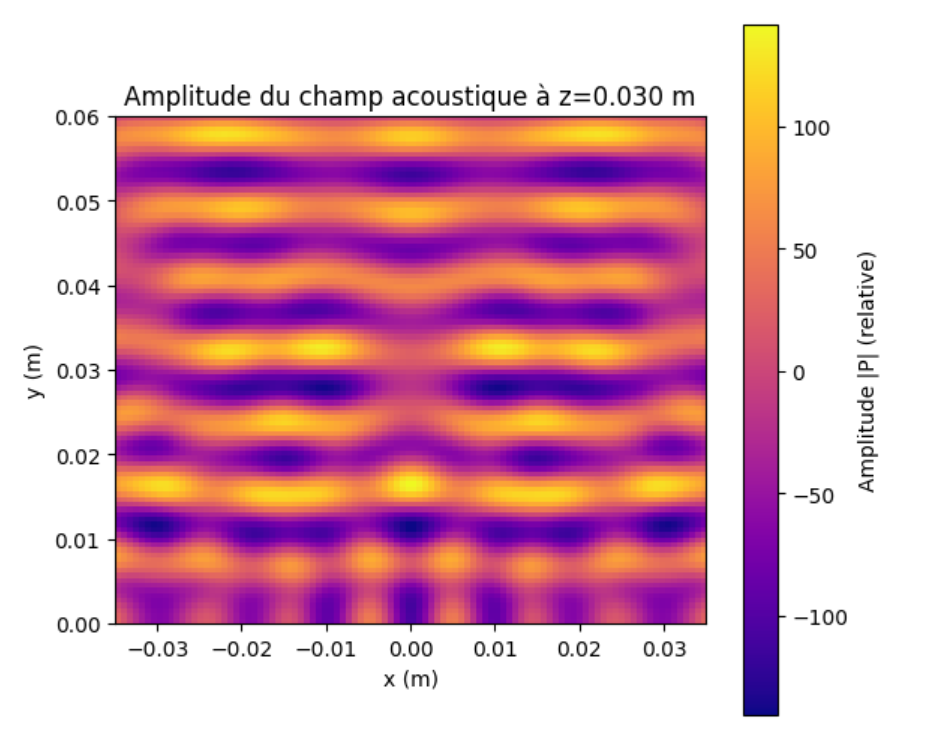
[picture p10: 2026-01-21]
Projet G1-G2/Lévitateur à une plaque/Physique théorique/Photos/optimizer 1 plaque (3).png

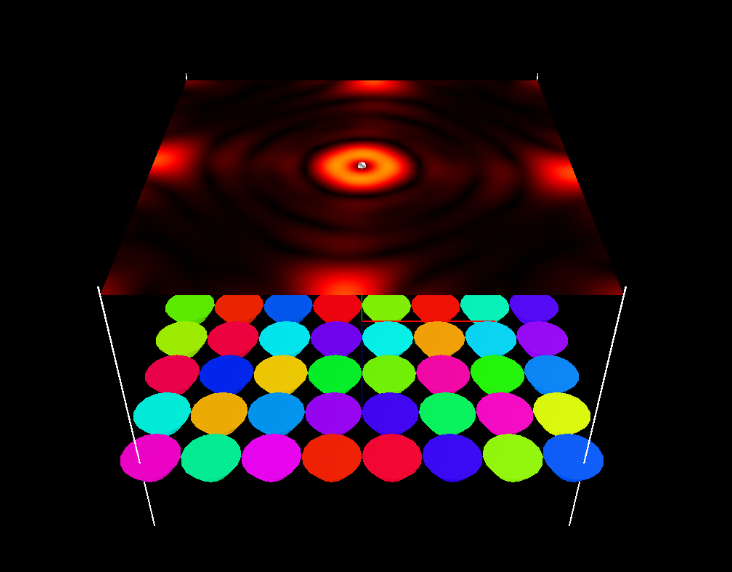
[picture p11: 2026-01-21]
Projet G1-G2/Lévitateur à une plaque/Informatique/Photos/vortex.png

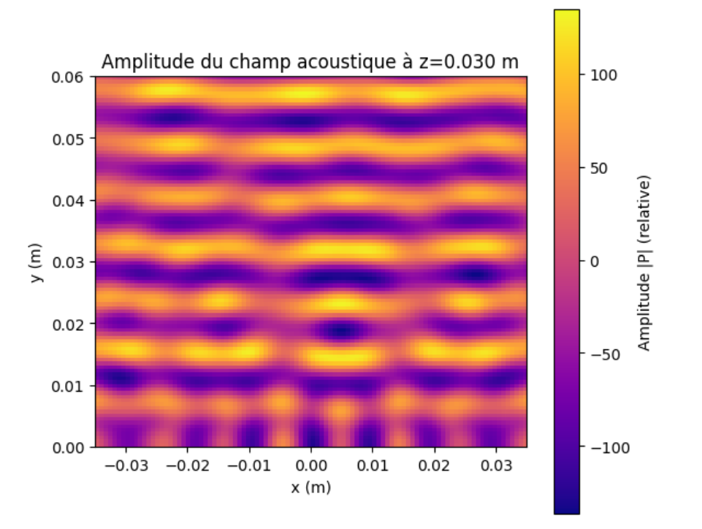
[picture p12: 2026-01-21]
Projet G1-G2/Lévitateur à une plaque/Physique théorique/Photos/vortex 1 plaque (3).png

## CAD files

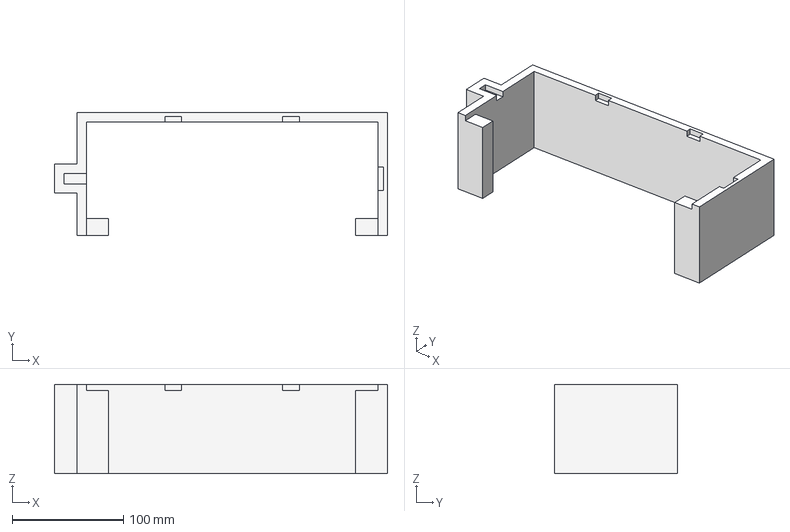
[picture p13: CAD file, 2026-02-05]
Projet G1-G2/Lévitateur à deux plaques/Conception Assistée par Ordinateur/Support Prototype 3.step
298.7 x 110.2 x 80.0 mm

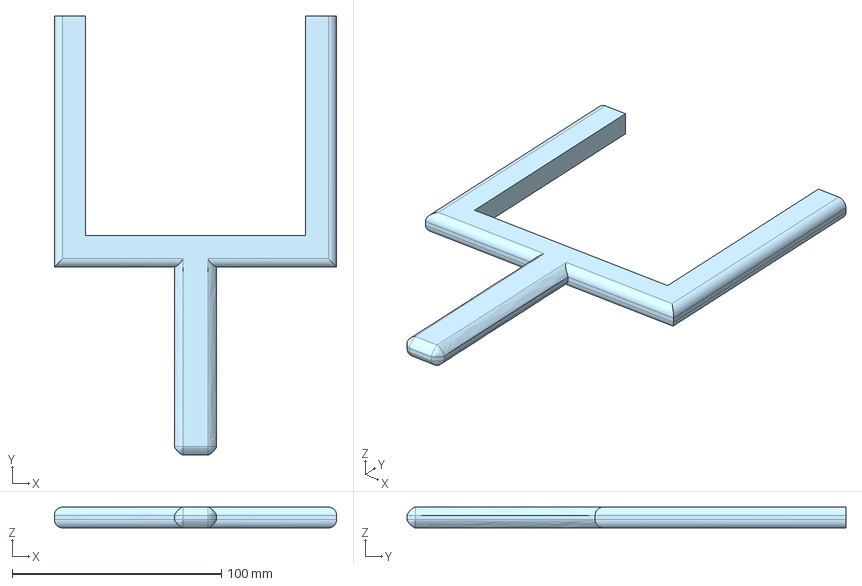
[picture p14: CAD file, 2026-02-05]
Projet G1-G2/Lévitateur à une plaque/Conception Assistée par Ordinateur/Pince.step
135.0 x 210.0 x 10.0 mm

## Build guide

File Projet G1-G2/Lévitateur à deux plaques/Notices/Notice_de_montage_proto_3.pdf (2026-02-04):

# NOTICE DE MONTAGE : LÉVITATEUR À DEUX PLAQUES

## Prototype 3 - Double matrice 8x8 en opposition

### 4 février 2026

## Sommaire

1 Introduction | 2
2 Étapes clés | 2
3 Liste du matériel et commande | 2
4 Conception et montage du prototype 3 | 2
5 Soudure et Montage des transducteurs | 4

## 1 Introduction

Le Prototype 3 est en quelques sortes une version dédoublée du Prototype 2, avec 2 plaques en opposition. Ainsi, les étapes de montage identiques à celles du prototype 2 ne sont pas reprises dans cette sous-section.

## 2 Étapes clés

1. Liste du matériel et commande
2. Conception et montage du prototype 3
3. Soudure des composants, montage des fils et des transducteurs

## 3 Liste du matériel et commande

Les composants nécessaires à la réalisation de ce prototype sont, à une différence près, les mêmes que ceux utilisés pour le Prototype 2, en quantité double.

Afin de disposer d’une amplitude de sortie d’environ 35 Vpp, les drivers TC4427CPA ont été remplacés par des transistors MOSFET IX4427NTR.

## 4 Conception et montage du prototype 3

Le concept du prototype 3 est de mettre deux plaques en vis-à-vis et de pouvoir régler la distance entre elles. C’est ce point qui a valu le plus de réflexion pour mettre au point un prototype qui règle la distance entre les deux plaques de manière continue.

Nous avons d’abord repris la plaque du prototype 2 que nous avons allongée et sur laquelle nous avons ajouté trois tiges filetées et une tige qui servira de règle.

Nous ajoutons aussi un support avec des encoches pour maintenir la plaque et un espace pour laisser passer les câbles électroniques. Nous avons choisi ce support pour avoir plus de stabilité qu’avec des pieds, car ce prototype va être plus long et plus lourd que le précédent.

Nous ajoutons également trois écrous qui se vissent sur les tiges filetées à n’importe quelle hauteur et qui vont assurer le fait qu’on peut régler la distance entre les plaques de manière continue.

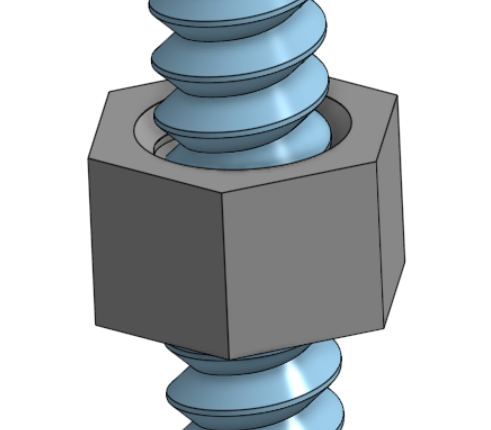
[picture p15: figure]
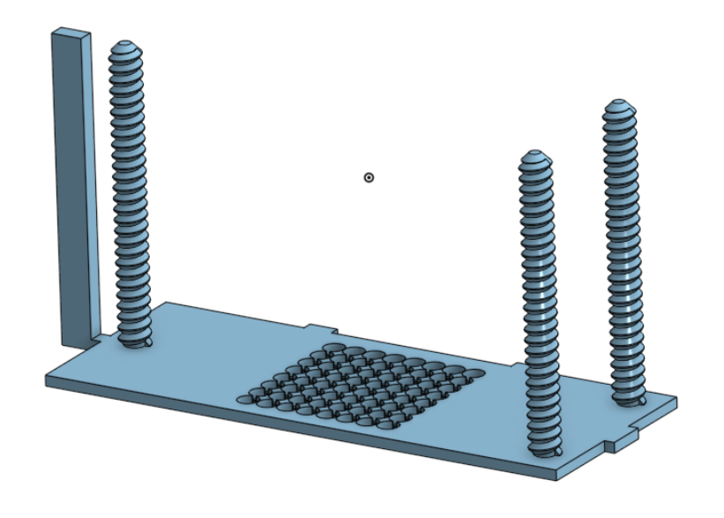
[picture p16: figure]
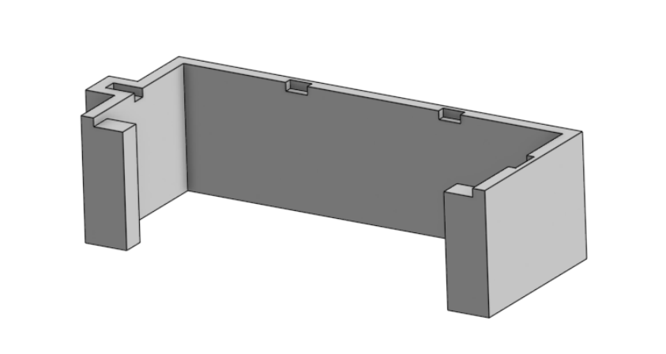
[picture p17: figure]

(a) Plaque basse - Onshape | (b) Support - Onshape | (c) Écrou - Onshape

Figure 1 – Pièces de la partie basse

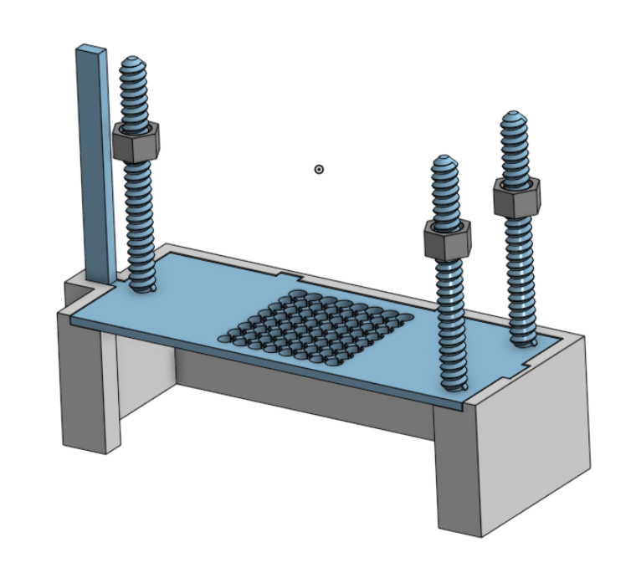
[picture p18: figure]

Figure 2 – Conception de la partie basse assemblée - Onshape

Pour la plaque supérieure en vis-à-vis, nous utilisons un design similaire à la plaque basse, mais les tiges filetées sont remplacées par des trous de passage d’un diamètre légèrement supérieur.

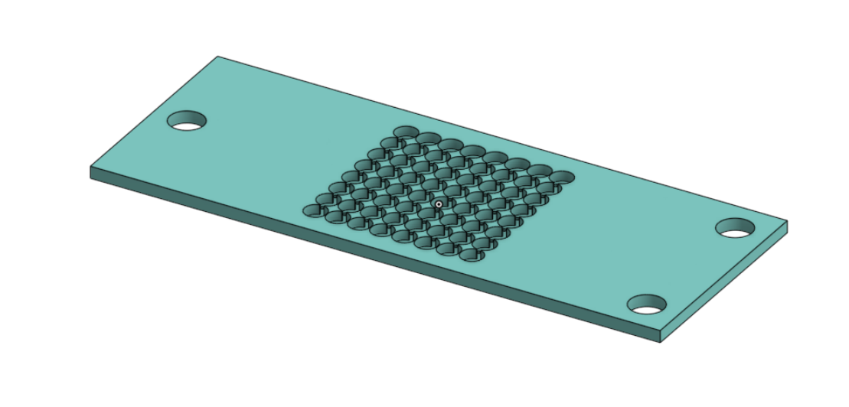
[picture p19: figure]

Figure 3 – Plaque haute - Onshape

Le montage final consiste à placer la plaque basse sur le support, ajuster les écrous à la hauteur souhaitée sur les tiges, et faire reposer la plaque haute sur ces derniers.

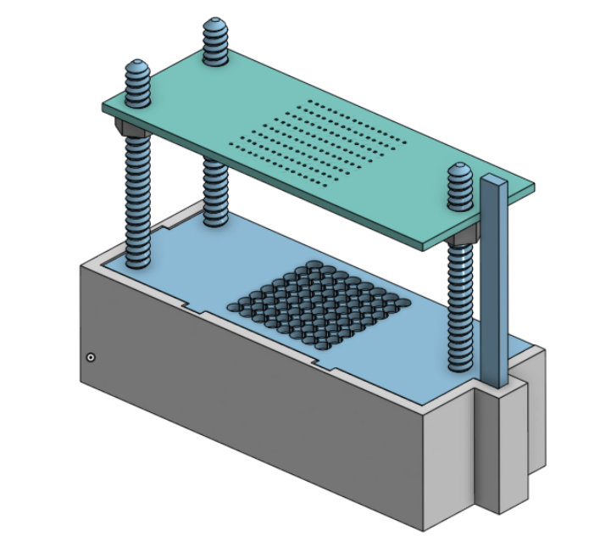
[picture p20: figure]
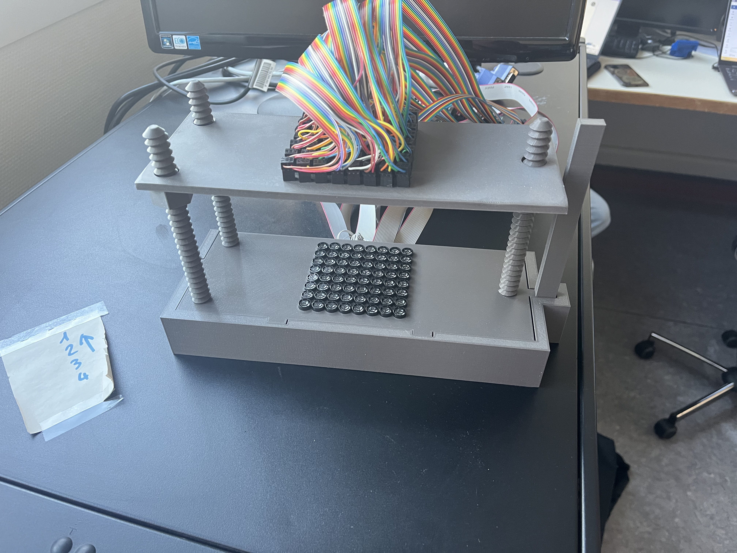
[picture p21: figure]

(a) Modélisation complète - Onshape | (b) Rendu réel après impression

Figure 4 – Montage final du prototype 3

## 5 Soudure et Montage des transducteurs

Les procédures de soudure (transistors MOSFET) et de montage des transducteurs (respect de la polarité) suivent la même méthodologie que celle décrite pour le Prototype 2, répétée pour les deux plaques.

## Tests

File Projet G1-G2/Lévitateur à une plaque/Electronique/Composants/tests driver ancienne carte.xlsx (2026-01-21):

Nb driver | Entrée A | Sortie A | Entrée B | Sortie B | Après changement
1 | ok | ok | ok | ok
2 | ok | ok | ok | ok
3 | ok | ok | ok | ok
4 | ok | ok | ok | ok
5 | ok | ok | ok | ok
6 | ok | ok | ok | ok
7 | ok | ok | ok | ok
8 | ok | ok | ok | ok
9 | ok | ok | ok | ok
10 | ok | ok | ok | ok
11 | ok | ok | ok | ok
12 | ok | ok | ok | ok
13 | ok | ok | ok | ok
14 | NON | NON | ok | ok
15 | ok | ok | ok | ok
16 | ok | ok | ok | ok
17 | NON | NON | NON | NON | tout ok
18 | ok | ok | ok | ok
19 | ok | ok | ok | ok
20 | ok | ok | ok | ok
21 | ok | ok | NON | NON | tout ok
22 | ok | ok | ok | ok
23 | ok | ok | ok | ok
24 | ok | ok | ok | ok
25 | ok | ok | ok | ok
26 | ok | NON | ok | ok | tout ok
27 | ok | ok | ok | ok
28 | ok | NON | ok | ok | tout ok
29 | ok | ok | ok | ok
30 | ok | ok | ok | ok
31 | ok | ok | ok | ok
32 | ok | ok | ok | ok

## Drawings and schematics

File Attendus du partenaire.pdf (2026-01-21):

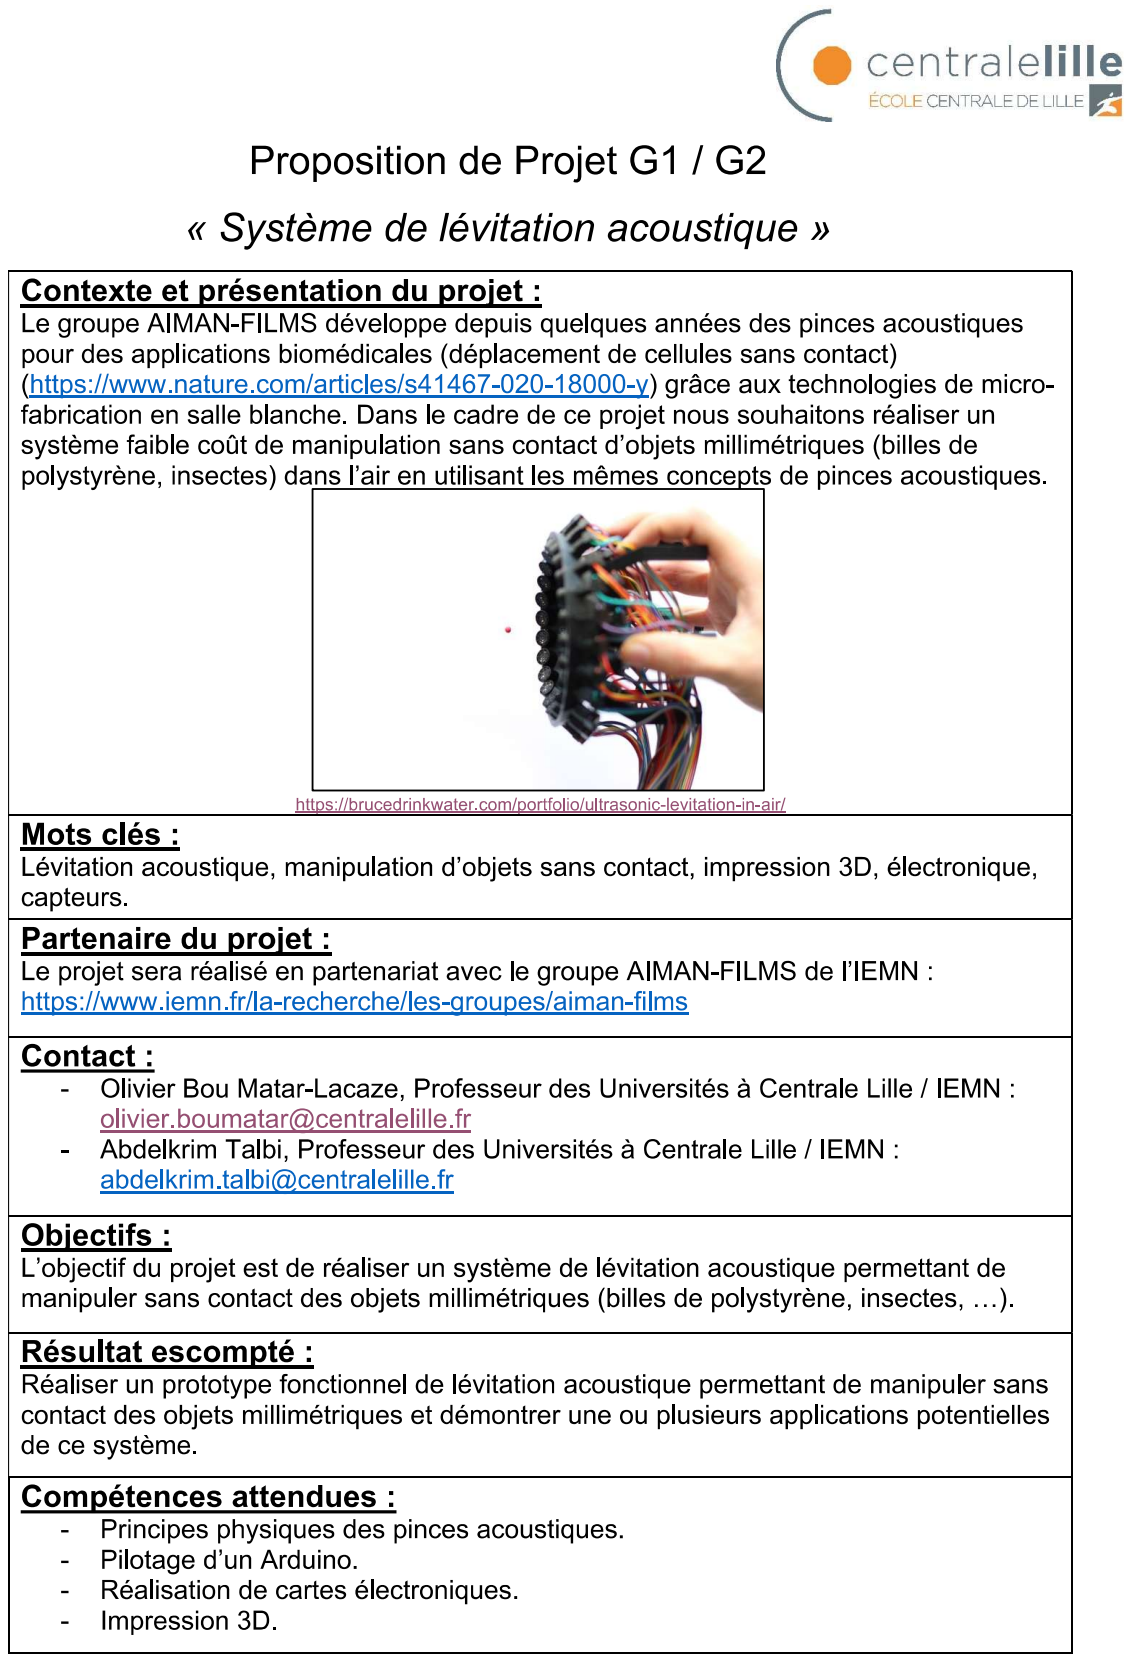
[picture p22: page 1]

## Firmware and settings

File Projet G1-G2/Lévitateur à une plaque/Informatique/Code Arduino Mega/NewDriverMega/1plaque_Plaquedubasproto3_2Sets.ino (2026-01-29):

#include <avr/sleep.h>
#include <avr/power.h>

#define N_PATTERNS 2
#define N_PORTS 10
#define N_DIVS 10
#define PATTERN_PERIODS 400000  // nombre de périodes 40 kHz avant de passer au pattern suivant donc là on fait 500000*1/40000 donc 12.5s

#define WAIT() __asm__ __volatile__("nop\n\t""nop\n\t""nop\n\t""nop\n\t""nop\n\t""nop\n\t""nop\n\t""nop\n\t""nop\n\t""nop\n\t""nop\n\t""nop\n\t""nop\n\t""nop\n\t")

#define OUTPUT_WAVE(pointer, d)  \
  PORTA = pointer[d*N_PORTS + 0]; \
  PORTC = pointer[d*N_PORTS + 1]; \
  PORTL = pointer[d*N_PORTS + 2]; \
  PORTB = pointer[d*N_PORTS + 3]; \
  PORTK = pointer[d*N_PORTS + 4]; \
  PORTF = pointer[d*N_PORTS + 5]; \
  PORTH = pointer[d*N_PORTS + 6]; \
  PORTD = pointer[d*N_PORTS + 7]; \
  PORTG = pointer[d*N_PORTS + 8]; \
  PORTJ = pointer[d*N_PORTS + 9];


static const byte patterns[N_PATTERNS * N_DIVS * N_PORTS] = {

  
 0x42, 0xEE, 0x42, 0xB5, 0x07, 0xDA, 0x69, 0x8A, 0x01, 0x02,
  0x45, 0xE9, 0x44, 0xB5, 0x17, 0xBA, 0x51, 0x86, 0x01, 0x02,
  0x5D, 0xE9, 0x45, 0xAD, 0x17, 0xA2, 0x11, 0x86, 0x01, 0x02,
  0xBD, 0xE9, 0x45, 0x4B, 0x1F, 0xA4, 0x12, 0x06, 0x04, 0x02,
  0xBD, 0xE9, 0xB5, 0x4A, 0x18, 0xA5, 0x12, 0x06, 0x06, 0x01,
  0xBD, 0x11, 0xBD, 0x4A, 0xF8, 0x25, 0x12, 0x05, 0x06, 0x01,
  0xBA, 0x16, 0xBB, 0x4A, 0xE8, 0x45, 0x2A, 0x09, 0x06, 0x01,
  0xA2, 0x16, 0xBA, 0x52, 0xE8, 0x5D, 0x6A, 0x09, 0x06, 0x01,
  0x42, 0x16, 0xBA, 0xB4, 0xE0, 0x5B, 0x69, 0x89, 0x03, 0x01,
  0x42, 0x16, 0x4A, 0xB5, 0xE7, 0x5A, 0x69, 0x89, 0x01, 0x02,


0x43, 0xEE, 0x5A, 0x35, 0x07, 0xDA, 0x69, 0x8F, 0x00, 0x02,
  0x44, 0xE8, 0x54, 0x35, 0x17, 0xBA, 0x51, 0x83, 0x00, 0x02,
  0x5C, 0xE9, 0x55, 0x2D, 0x17, 0xA2, 0x10, 0x83, 0x00, 0x02,
  0xBC, 0xE9, 0x55, 0xCB, 0x1F, 0xA5, 0x12, 0x03, 0x05, 0x02,
  0xBC, 0xE9, 0xA5, 0xCA, 0x18, 0xA5, 0x12, 0x03, 0x07, 0x01,
  0xBC, 0x11, 0xA5, 0xCA, 0xF8, 0x25, 0x12, 0x00, 0x07, 0x01,
  0xBB, 0x17, 0xAB, 0xCA, 0xE8, 0x45, 0x2A, 0x0C, 0x07, 0x01,
  0xA3, 0x16, 0xAA, 0xD2, 0xE8, 0x5D, 0x6B, 0x0C, 0x07, 0x01,
  0x43, 0x16, 0xAA, 0x34, 0xE0, 0x5A, 0x69, 0x8C, 0x02, 0x01,
  0x43, 0x16, 0x5A, 0x35, 0xE7, 0x5A, 0x69, 0x8C, 0x00, 0x02
    };

static byte bufferA[N_DIVS * N_PORTS];
static byte bufferB[N_DIVS * N_PORTS];

void setup() {
  // --- Configuration des ports en sortie ---
  DDRA = DDRC = DDRL = DDRB = DDRK = DDRF = DDRH = DDRD = DDRG = DDRJ = 0xFF;
  PORTA = PORTC = PORTL = PORTB = PORTK = PORTF = PORTH = PORTD = PORTG = PORTJ = 0x00;

  //clear the buffers
  for (int i = 0; i < (N_PATTERNS * N_DIVS * N_PORTS); ++i) {
    bufferA[i] = 0;
    bufferB[i] = 0;
  }

  //initial pattern ==> sinus avec toute les sorties qui sont en phases
  for (int i = 0; i < (N_PORTS*N_DIVS/2); ++i){
     bufferA[i] = 0xFF;
  }

  // --- PWM 40 kHz sur pin 2 ---
  pinMode(2, OUTPUT);
  noInterrupts();
  TCCR3A = bit(WGM10) | bit(WGM11) | bit(COM1B1);
  TCCR3B = bit(WGM12) | bit(WGM13) | bit(CS10);
  OCR3A = (F_CPU / 40000L) - 3;
  OCR3B = (F_CPU / 40000L) / 2;
  interrupts();

  // --- Sync in pin ---
  pinMode(3, INPUT_PULLUP); // connectée à pin 2 pour synchro

  // --- Désactivation des périphériques inutiles ---
  ADCSRA = 0;
  power_adc_disable();
  power_spi_disable();
  power_twi_disable();
  power_timer0_disable();
  power_usart1_disable();
  power_usart2_disable();
  power_usart3_disable();

  // L'idée est la suivante : on parcourt "patterns" par pas de N_Div * N_ports avec deux buffers comme avant, un lecture et un écriture
  // La variable de ce code est donc le timing que l'on souhaite entre chaque chgmt de pattern = "pattern_periods"

  bool useA = true;
  unsigned long currentPeriods = 0;
  byte currentPatternIndex = 0;  // index du pattern courant dans patterns

  byte* activeBuffer = bufferA;
  byte* nextBuffer   = bufferB;

  // copie initiale du premier pattern dans bufferA
  for(int i=0; i<N_PORTS*N_DIVS; i++)
      bufferA[i] = patterns[i];

  // pré-remplissage du bufferB avec le pattern suivant
  for(int i=0; i<N_PORTS*N_DIVS; i++)
      bufferB[i] = patterns[(currentPatternIndex + 1) * N_PORTS * N_DIVS + i];

  byte* emittingPointerH = &activeBuffer[0];
  byte* emittingPointerL = &activeBuffer[N_PORTS * N_DIVS / 2];

  LOOP:
    while (PINE & 0b00100000); // attente synchro

    OUTPUT_WAVE(emittingPointerH, 0); WAIT();
    OUTPUT_WAVE(emittingPointerH, 1); WAIT();
    OUTPUT_WAVE(emittingPointerH, 2); WAIT();
    OUTPUT_WAVE(emittingPointerH, 3); WAIT();
    OUTPUT_WAVE(emittingPointerL, 0); WAIT();
    OUTPUT_WAVE(emittingPointerL, 1); WAIT();
    OUTPUT_WAVE(emittingPointerL, 2); WAIT();
    OUTPUT_WAVE(emittingPointerL, 3); WAIT();

    // incrémente compteur de périodes
    currentPeriods++;
    if(currentPeriods >= PATTERN_PERIODS) {
        currentPeriods = 0;

        // switch des buffers
        useA = !useA;
        activeBuffer = useA ? bufferA : bufferB;
        nextBuffer   = useA ? bufferB : bufferA;

        // avance pattern
        currentPatternIndex++;
        if(currentPatternIndex >= N_PATTERNS) currentPatternIndex = 0;

        // met à jour pointeurs pour le buffer actif
        emittingPointerH = &activeBuffer[0];
        emittingPointerL = &activeBuffer[N_PORTS * N_DIVS / 2];

        // prépare le prochain pattern dans le buffer inactif
        int nextPatternIndex = currentPatternIndex + 1;
        if(nextPatternIndex >= N_PATTERNS) nextPatternIndex = 0;

        for(int i=0; i<N_PORTS*N_DIVS; i++)
            nextBuffer[i] = patterns[nextPatternIndex * N_PORTS * N_DIVS + i];
    }

    goto LOOP;
}

// Boucle Arduino vide (jamais utilisée)
void loop() {}

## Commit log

2026-01-29 Update and rename Projet G1-G2/Lévitateur à une plaque/Informatique/Code Arduino Mega/Plaquebasproto3ComparaisonschgmtparamsVortexL6.ino to Projet G1-G2/Lévitateur à une plaque/Informatique/Code Ardu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
2026-01-29 Update and rename Projet G1-G2/Lévitateur à une plaque/Informatique/Code Arduino Mega/Plaquedubasproto3ComparaisonschgmtsMehdi.ino to Projet G1-G2/Lévitateur à une plaque/Informatique/Code Arduino Me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
2026-02-04 Update and rename Projet G1-G2/Lévitateur à une plaque/Informatique/Code Arduino Mega/DriverMEGA.ino to Projet G1-G2/Lévitateur à une plaque/Informatique/Code Arduino Mega/DriverMega/DriverMEGA.ino
2026-02-04 Rename Projet G1-G2/Lévitateur à deux plaques/Informatique/Carte_maitre.ino to Projet G1-G2/Lévitateur à deux plaques/Informatique/Communication 2 Arduino/Carte_maitre.ino
2026-02-05 Rename Projet G1-G2/Lévitateur à une plaque/Pince.step to Projet G1-G2/Lévitateur à une plaque/Conception Assistée par Ordinateur/Pince.step
    [Pince.step]
2026-02-05 Rename Projet G1-G2/Lévitateur à deux plaques/Support Prototype 3.step to Projet G1-G2/Lévitateur à deux plaques/Conception Assistée par Ordinateur/Support Prototype 3.step
    [Support Prototype 3.step]
